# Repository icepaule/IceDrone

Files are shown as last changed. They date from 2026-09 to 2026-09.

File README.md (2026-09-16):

# IceDrone

A small, 3D-printable brushed quadcopter built around the **Seeed Studio XIAO ESP32-S3 Sense**, a **GY-91 IMU**, **VL6180X ToF sensor**, four **8520 brushed coreless motors** and 75/76 mm propellers. The project combines an Open32Drone-derived flight stack with Wi-Fi camera streaming and a modular printable airframe sized for an **Anycubic Kobra S1**.

> **Current mechanical design: Airframe V2.**  
> **Current electrical design: V3.4 HW-VERIFIED.** V3.2/V3.3 drawings are obsolete for soldering.  
> Full documentation: **[icepaule.github.io/IceDrone](https://icepaule.github.io/IceDrone/)** and [`docs/`](docs/).

## Electrical V3.4

The current 70×30 mm perfboard prototype and the custom-PCB path share the same V3.4 electrical profile:

- M1 rear-left: GPIO4 / D3
- M2 rear-right: **GPIO44 / D7**
- M3 front-right: GPIO6 / D5
- M4 front-left: GPIO5 / D4
- I2C: SDA GPIO2 / D1, SCL GPIO43 / D6; firmware uses `Wire.begin(2, 43)`
- motor flyback: SS34-class ≥3 A Schottky
- C1: 470 µF / 10 V low-ESR
- C2: 100 µF / 10 V low-ESR
- raw 1S LiHV is **not** fed directly into XIAO 5V/BAT; V3.4 uses an off-board 1S→5 V boost followed by D5
- photographed VL6180X order: `VIN | 2V8 | GND | GPIO | SHDN | SCL | SDA`

For the temporary perfboard build use **[`docs/10_PERFBOARD_V34_SOLDERING_DE.md`](docs/10_PERFBOARD_V34_SOLDERING_DE.md)** and the machine-readable files in `hardware/`.

## Airframe V2

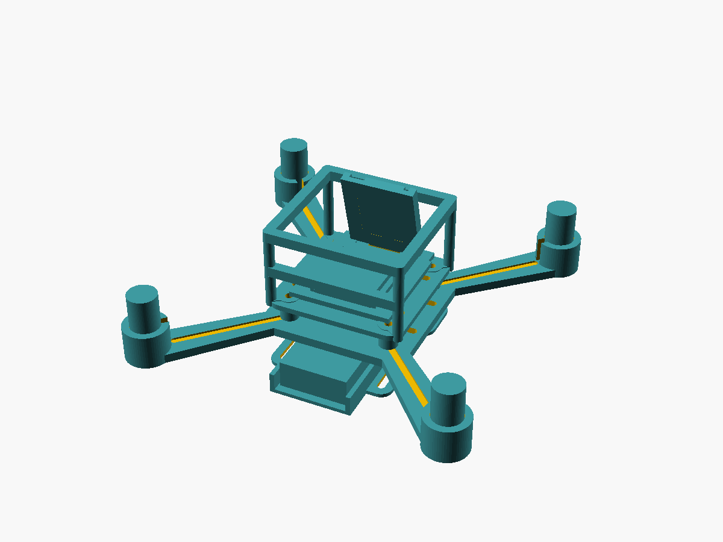
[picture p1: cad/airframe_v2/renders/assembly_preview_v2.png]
IceDrone Airframe V2 assembly


The current airframe is a modular **123 mm Quad-X** design with dedicated mounts for the 1S battery, electronics deck, XIAO ESP32-S3 Sense camera board, GY-91 IMU and a lightweight flight cage or closed canopy.

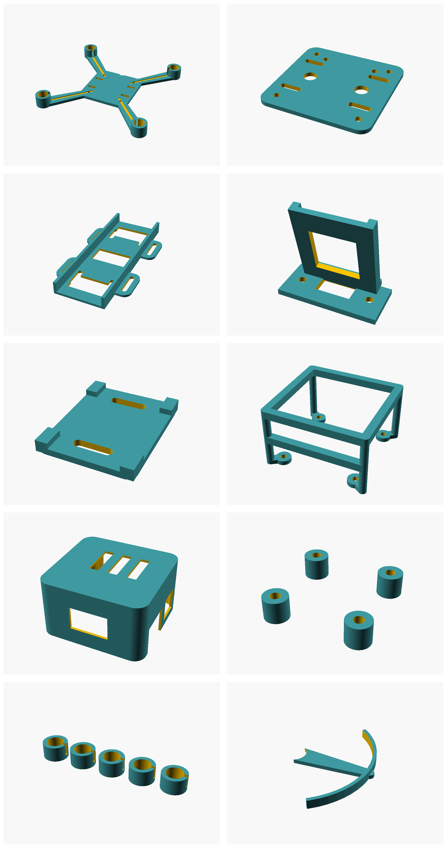
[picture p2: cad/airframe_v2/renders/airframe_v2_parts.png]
Airframe V2 printable parts


Detailed part descriptions, OpenSCAD sources, STL downloads, Kobra S1 print settings and validation notes are in **[`cad/airframe_v2/`](cad/airframe_v2/)**.

### Main printable parts

| Part | Preview | Source / STL |
|---|---|---|
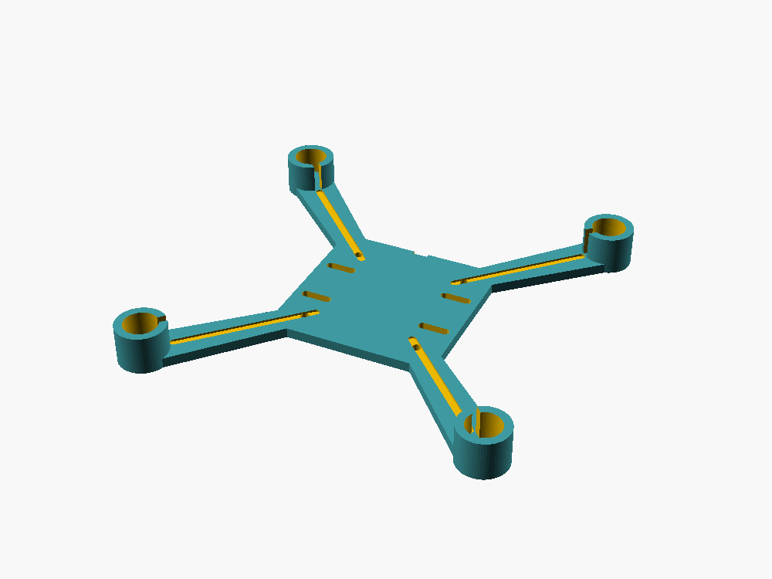
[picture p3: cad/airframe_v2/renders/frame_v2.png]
| Main Quad-X frame |  | [`frame_v2.scad`](cad/airframe_v2/scad/frame_v2.scad) · [`frame_v2.stl`](cad/airframe_v2/stl/frame_v2.stl) |
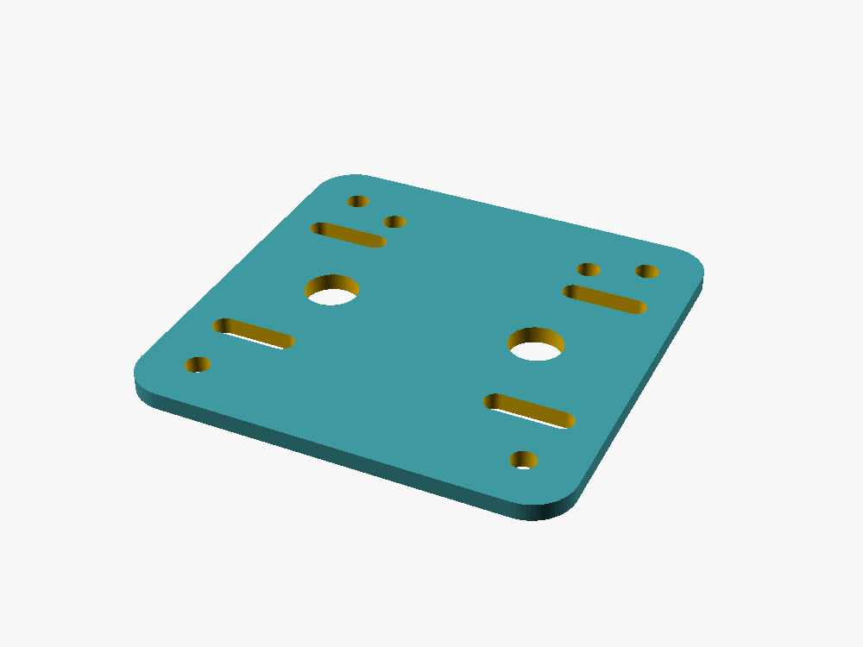
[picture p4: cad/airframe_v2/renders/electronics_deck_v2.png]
| Electronics deck |  | [`electronics_deck_v2.scad`](cad/airframe_v2/scad/electronics_deck_v2.scad) · [`electronics_deck_v2.stl`](cad/airframe_v2/stl/electronics_deck_v2.stl) |
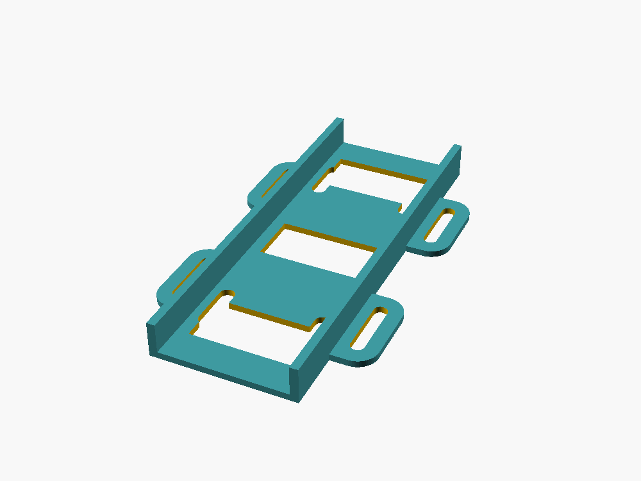
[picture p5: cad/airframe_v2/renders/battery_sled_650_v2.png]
| Battery sled |  | [`battery_sled_650_v2.scad`](cad/airframe_v2/scad/battery_sled_650_v2.scad) · [`battery_sled_650_v2.stl`](cad/airframe_v2/stl/battery_sled_650_v2.stl) |
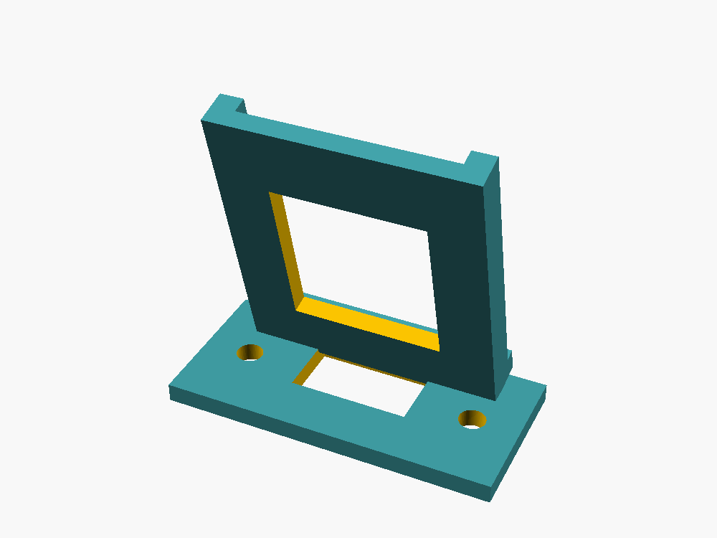
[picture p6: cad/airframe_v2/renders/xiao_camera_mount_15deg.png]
| XIAO camera mount |  | [`xiao_camera_mount_15deg.scad`](cad/airframe_v2/scad/xiao_camera_mount_15deg.scad) · [`xiao_camera_mount_15deg.stl`](cad/airframe_v2/stl/xiao_camera_mount_15deg.stl) |
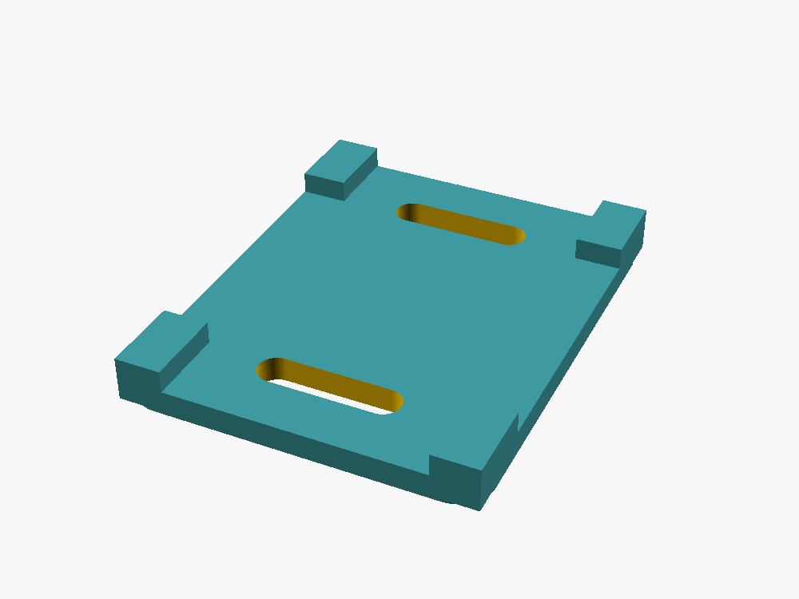
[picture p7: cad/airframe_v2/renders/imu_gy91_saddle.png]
| GY-91 IMU saddle |  | [`imu_gy91_saddle.scad`](cad/airframe_v2/scad/imu_gy91_saddle.scad) · [`imu_gy91_saddle.stl`](cad/airframe_v2/stl/imu_gy91_saddle.stl) |
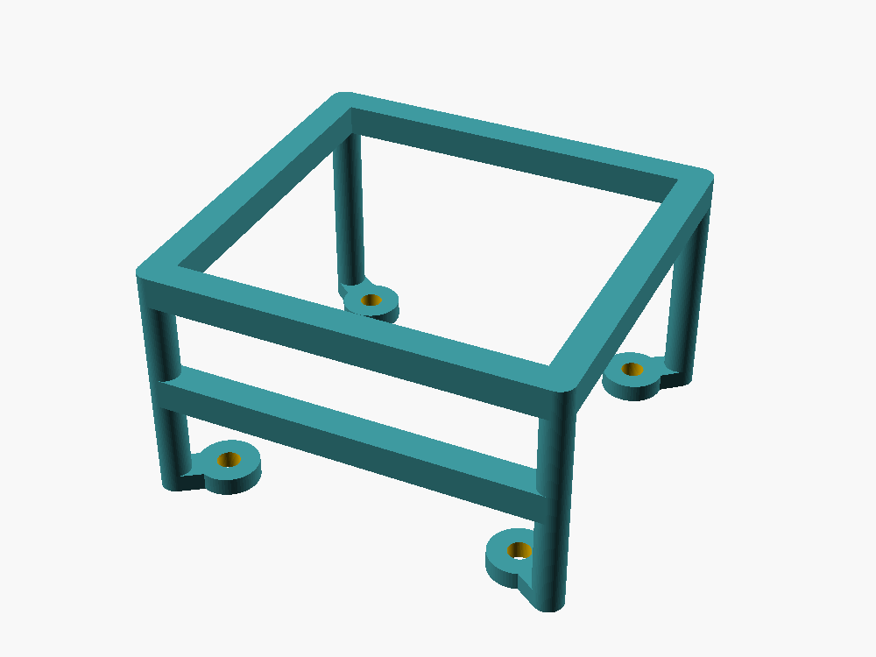
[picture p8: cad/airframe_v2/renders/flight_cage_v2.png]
| Flight cage |  | [`flight_cage_v2.scad`](cad/airframe_v2/scad/flight_cage_v2.scad) · [`flight_cage_v2.stl`](cad/airframe_v2/stl/flight_cage_v2.stl) |
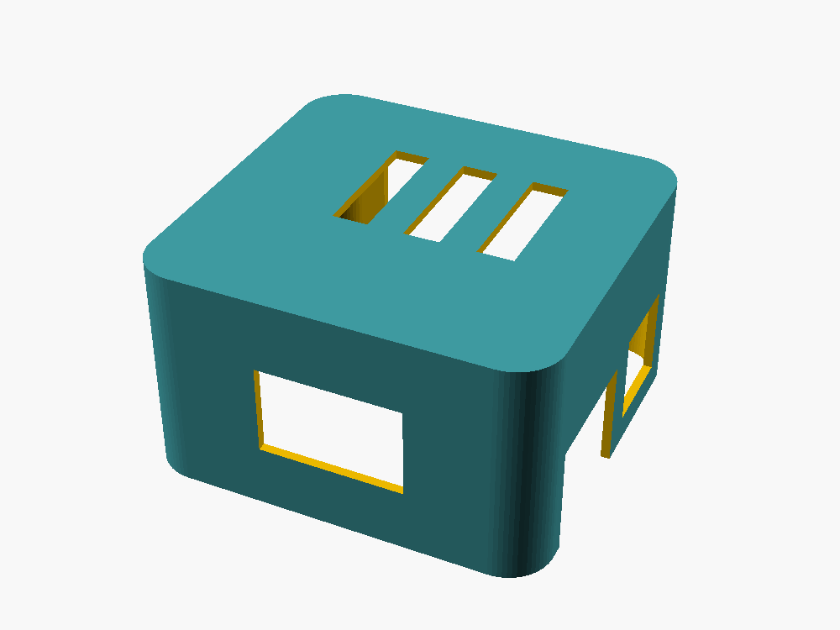
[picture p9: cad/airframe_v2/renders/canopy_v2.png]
| Closed canopy |  | [`canopy_v2.scad`](cad/airframe_v2/scad/canopy_v2.scad) · [`canopy_v2.stl`](cad/airframe_v2/stl/canopy_v2.stl) |
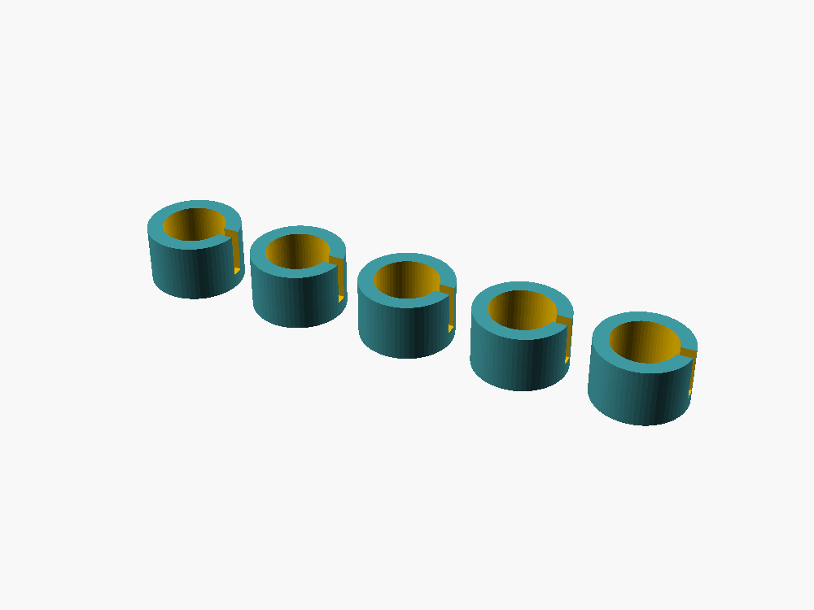
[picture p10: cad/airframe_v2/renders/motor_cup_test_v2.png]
| Motor-cup fit test |  | [`motor_cup_test_v2.scad`](cad/airframe_v2/scad/motor_cup_test_v2.scad) · [`motor_cup_test_v2.stl`](cad/airframe_v2/stl/motor_cup_test_v2.stl) |

## Propellers and replacement CAD

The purchased 75 mm propellers can be used directly. Parametric replacement/test models are kept separately under [`cad/propellers/`](cad/propellers/) so the flight airframe and experimental propeller work remain clearly separated.

| Standard 75 mm | Experimental toroidal / low-noise concept |
|---|---|
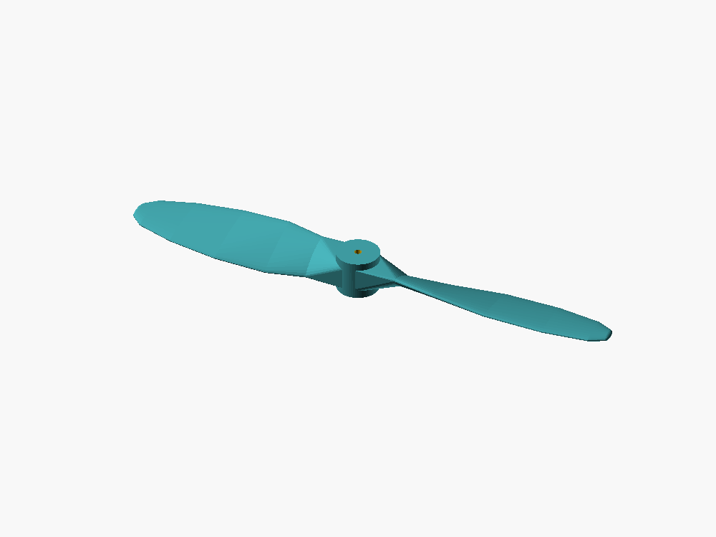
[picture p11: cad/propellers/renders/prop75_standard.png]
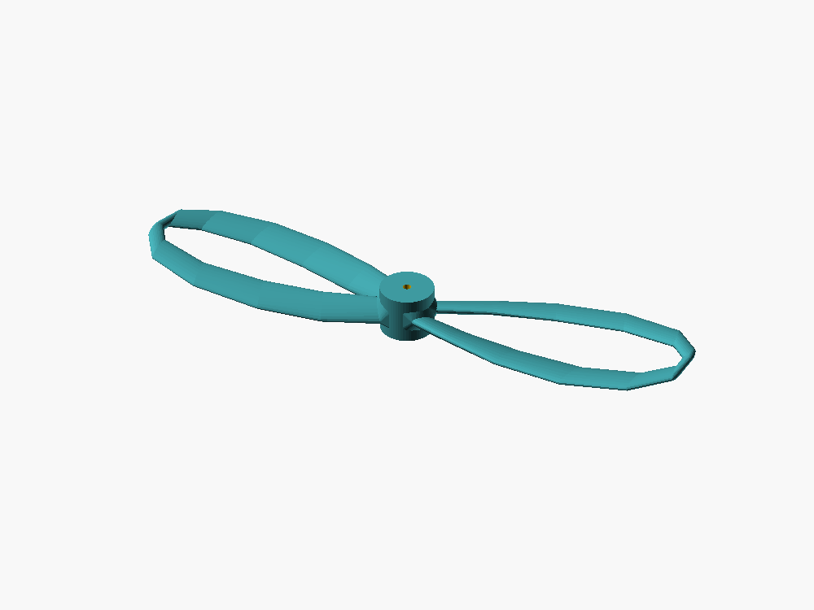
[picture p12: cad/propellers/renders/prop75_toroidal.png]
|  |  |

The repository includes CW/CCW STL exports and a 1 mm shaft-fit coupon. The toroidal model is experimental and should be bench-tested for current draw, vibration, balance and thrust before flight use.

## Design goals

- mostly printable micro quadcopter
- **123 mm diagonal motor-center wheelbase**
- **8520 brushed motors**, nominal 1.0 mm shafts
- **75/76 mm two-blade CW/CCW propellers**
- target takeoff mass around **60–80 g**
- XIAO ESP32-S3 Sense as flight/camera computer
- QVGA MJPEG live video over 2.4 GHz Wi-Fi
- MAVLink telemetry/control over UDP 14550
- stabilized/manual first-flight target
- printable on an Anycubic Kobra S1 with a 0.4 mm nozzle

## Repository layout

```text
.
├── README.md
├── bom/
├── cad/
│   ├── airframe_v2/
│   │   ├── scad/
│   │   ├── stl/
│   │   └── renders/
│   └── propellers/
│       ├── scad/
│       ├── stl/
│       └── renders/
├── docs/
├── firmware/
└── hardware/
```

## Quick start

1. Read [`docs/01_BOM.md`](docs/01_BOM.md) and [`docs/02_ELECTRICAL.md`](docs/02_ELECTRICAL.md); V3.4 is authoritative.
2. If building the temporary 70×30 mm perfboard, follow [`docs/10_PERFBOARD_V34_SOLDERING_DE.md`](docs/10_PERFBOARD_V34_SOLDERING_DE.md) hole by hole and multimeter-test each stage.
3. Print [`cad/airframe_v2/stl/motor_cup_test_v2.stl`](cad/airframe_v2/stl/motor_cup_test_v2.stl) before committing to the full frame.
4. Print the Airframe V2 parts using the settings in [`docs/03_MECHANICAL.md`](docs/03_MECHANICAL.md).
5. Assemble and power electronics **without propellers**, following [`docs/05_BUILD_AND_TEST.md`](docs/05_BUILD_AND_TEST.md).
6. Run the V3.4 bench firmware in [`firmware/bench_test/`](firmware/bench_test/) and verify IMU orientation and every motor channel.
7. Only after all bench checks pass, install balanced propellers and continue with [`docs/06_FIRST_FLIGHT.md`](docs/06_FIRST_FLIGHT.md).

## Primary references

- Open32Drone: https://github.com/npu-ius-lab/open32drone
- ESP-FLY: https://github.com/Seeed-Projects/Co-Create_ESP-FLY
- XIAO ESP32-S3 Sense: https://wiki.seeedstudio.com/xiao_esp32s3_getting_started/

## Important safety rule

**Never test motor channels, arming logic, mixer direction or firmware changes with propellers fitted.** Verify motor order and direction at low output first. Printed propellers in particular require careful balancing and restrained bench testing before flight.

## License and attribution

Project documentation, original CAD and bench-test code are provided under Apache-2.0 unless a file states otherwise. Open32Drone source is not duplicated here. See [`NOTICE`](NOTICE) and [`LICENSE`](LICENSE).

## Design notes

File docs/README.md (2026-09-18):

# IceDrone Documentation

IceDrone is a small, 3D-printable brushed quadcopter built around the **Seeed Studio XIAO ESP32-S3 Sense**, **GY-91 IMU**, VL6180X ToF sensor, 8520 motors and the current **Airframe V2** mechanical stack.

Airframe V2 assembly

This documentation belongs to [github.com/icepaule/IceDrone](https://github.com/icepaule/IceDrone) and is also published at **[icepaule.github.io/IceDrone](https://icepaule.github.io/IceDrone/)**.

## Table of contents

| # | Chapter | Covers |
|---:|---|---|
| 01 | [Bill of Materials](01_BOM.md) | Current V3.4 parts and electrical requirements |
| 02 | [Electrical](02_ELECTRICAL.md) | V3.4 power architecture, motor stages, pin map, sensors |
| 03 | [Mechanical](03_MECHANICAL.md) | Airframe V2, printable parts, STL/SCAD, Kobra S1 settings, CG |
| 04 | [Firmware](04_FIRMWARE.md) | Open32Drone strategy, build settings, video/MAVLink design rules |
| 05 | [Build and Test](05_BUILD_AND_TEST.md) | Step-by-step assembly and bring-up |
| 06 | [First Flight](06_FIRST_FLIGHT.md) | Test environment, hop/hover phases, acceptance criteria |
| 07 | [Safety and Legal (DE/EU)](07_SAFETY_AND_LEGAL_DE.md) | Workshop safety and UAS legal notes |
| 08 | [Troubleshooting](08_TROUBLESHOOTING.md) | Common faults and causes |
| 09 | [Amazon.de Order List (DE)](09_AMAZON_ORDER_LIST_DE.md) | Dated marketplace shopping aid |
| 10 | [Perfboard V3.4 soldering (DE)](10_PERFBOARD_V34_SOLDERING_DE.md) | Hole-by-hole solder map, SMD practice, multimeter gates |
| 11 | [PCB-Reflow Sn42Bi58 (DE)](11_REFLOW_SN42BI58_DE.md) | Stencil, paste printing, YIHUA YH-853AAA profile, inspection |
| — | [Reflow Quick Card](REFLOW_QUICK_CARD_DE.md) | Condensed workbench checklist |
| — | [Sources](SOURCES.md) | Upstream projects and references |

## Current project status

| Area | Status |
|---|---|
| Electrical revision | **V3.4 HW-VERIFIED is authoritative**; V3.2/V3.3 are obsolete for soldering |
| Perfboard prototype | 70×30 mm V3.4 layout and detailed solder guide available |
| Custom PCB | **70×30 mm PCB and stencil received**; manual first-article assembly/reflow procedure documented |
| Reflow process | Sn42Bi58 low-temperature workflow for YIHUA YH-853AAA documented; separate `bom/reflow_bom.csv` available |
| Bill of materials | Updated for SS34-class motor flyback, 10 V bulk capacitors and regulated XIAO 5 V supply |
| Mechanical | **Airframe V2 current**; parametric OpenSCAD + STL + previews in `cad/airframe_v2/` |
| Propeller CAD | Standard and experimental toroidal models in `cad/propellers/` |
| Bench-test firmware | Available in `firmware/bench_test/`; V3.4 motor map uses GPIO4/44/6/5 |
| Camera Wi-Fi diagnostic | `firmware/camera_wifi_test/` streams MJPEG over the existing Wi-Fi LAN |
| Flight-critical firmware | Tracks upstream Open32Drone; motor mapping/rotation, IMU calibration and battery calibration still require full hardware bring-up |

## V3.4 electrical highlights

- M1 GPIO4/D3
- M2 **GPIO44/D7**
- M3 GPIO6/D5
- M4 GPIO5/D4
- I2C SDA GPIO2/D1, SCL GPIO43/D6; firmware must call `Wire.begin(2, 43)`
- D1-D4 = SS34-class ≥3 A Schottky
- C1 = 470 µF / 10 V low-ESR
- C2 = 100 µF / 10 V low-ESR
- raw LiHV is not connected directly to XIAO 5V/BAT; use 1S→5 V boost + D5
- photographed VL6180X order: VIN, 2V8, GND, GPIO, SHDN, SCL, SDA

## Related files

- [`../hardware/perfboard_v34_netlist.csv`](../hardware/perfboard_v34_netlist.csv) — authoritative perfboard connections
- [`../hardware/perfboard_v34_pin_matrix.csv`](../hardware/perfboard_v34_pin_matrix.csv) — V3.4 external pin map
- [`assets/perfboard_v34_solder_side.svg`](assets/perfboard_v34_solder_side.svg) — physically mirrored rear-view solder map
- [`../hardware/pinmap.csv`](../hardware/pinmap.csv) — XIAO/GPIO mapping
- [`../hardware/motor_stage_netlist.csv`](../hardware/motor_stage_netlist.csv) — motor/power component netlist
- [`../bom/reflow_bom.csv`](../bom/reflow_bom.csv) — tools/consumables for stencil + Sn42Bi58 reflow
- [`assets/stencil_setup_v34.svg`](assets/stencil_setup_v34.svg) — oversized-stencil setup
- [`assets/reflow_profile_sn42bi58.svg`](assets/reflow_profile_sn42bi58.svg) — low-temperature profile reference
- [`assets/reflow_real_stencil_fixture_v34.jpg`](assets/reflow_real_stencil_fixture_v34.jpg) — real stencil/clamping setup
- [`assets/reflow_real_yihua_setup_v34.jpg`](assets/reflow_real_yihua_setup_v34.jpg) — real YIHUA setup / mechanical fit reference
- [`../firmware/bench_test/`](../firmware/bench_test/) — pre-flight bench firmware
- [`../cad/airframe_v2/`](../cad/airframe_v2/) — current airframe CAD
- [`../LICENSE`](../LICENSE), [`../NOTICE`](../NOTICE) — licensing

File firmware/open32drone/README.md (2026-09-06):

# Open32Drone integration

`vendor/open32drone` is a git submodule pointing at the upstream
[Open32Drone](https://github.com/npu-ius-lab/open32drone) repository. Do not edit
files inside the submodule directly — apply `v1.patch` on top of a clean
checkout instead, so upstream updates (`git submodule update --remote`) stay a
clean rebase target.

## What `v1.patch` changes

Applies the two "Local V1 choices" from `docs/04_FIRMWARE.md` that differ from
upstream's own defaults:

- `CAMERA_JPEG_QUALITY`: 10 → 18
- `OPTICAL_FLOW_ENABLED`: 1 → 0 (disabled for V1)

Everything else in that policy list (MAVLink port 14550, camera enabled,
QVGA, one viewer maximum, SBUS disabled, battery divider 2.0) already matches
upstream's defaults and needs no patch.

## Build and flash

```bash
# from the repo root, once:
git submodule update --init vendor/open32drone

cd vendor/open32drone
git apply ../../firmware/open32drone/v1.patch
cd software

arduino-cli core install esp32:esp32@3.3.6 \
  --additional-urls https://espressif.github.io/arduino-esp32/package_esp32_index.json
arduino-cli lib install "FlixPeriph@1.10.4" "MAVLink@2.0.25"

arduino-cli compile --clean \
  --fqbn 'esp32:esp32:XIAO_ESP32S3:PSRAM=opi,PartitionScheme=default_8MB,FlashMode=dio' \
  --output-dir /tmp/open32drone-build firmware

arduino-cli upload -p /dev/ttyACM0 \
  --fqbn 'esp32:esp32:XIAO_ESP32S3:PSRAM=opi,PartitionScheme=default_8MB,FlashMode=dio' \
  --input-dir /tmp/open32drone-build

# afterwards, restore the clean submodule checkout:
cd ../../..
git -C vendor/open32drone checkout -- .
```

## Verified 2026-09-06 (USB-only smoke test, submodule at `a49c037a`)

No IMU, motors, or battery wired — camera and Wi-Fi hardware only, propellers
off. Boot log confirmed:

- `Camera profile: QVGA quality 18, 10 FPS` — patch applied correctly.
- `softAP started: yes (IP 192.168.4.1)`, `Camera stream: http://192.168.4.1/stream`.
- `MAVLink UDP: bind OK local 14550 initial peer 192.168.4.255:14550`.
- `IMU: Error: 1` / `IMU initialization failed` — expected, no IMU wired yet
  (GY-91 arrives ~2026-09-16/21).
- No optical-flow setup attempted (`OPTICAL_FLOW_ENABLED=0` took effect).
- `Initializing complete`, then the CLI banner — firmware runs its full
  300 Hz loop without an IMU or optical flow present; nothing hangs or
  crash-loops on the missing sensors.

This only proves the firmware boots and its Wi-Fi/camera/MAVLink transport
work on this board. It is not a flight readiness check — Stages E through J
in `docs/05_BUILD_AND_TEST.md` (IMU orientation, motor mapping/rotation,
battery calibration, pre-prop checklist) still apply once the IMU and motor
hardware are installed.

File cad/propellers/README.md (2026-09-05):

# IceDrone 75 mm Propeller CAD

Parametric replacement and experimental propeller models for the 8520 brushed motor configuration used by IceDrone. The purchased molded 75 mm propellers remain the preferred baseline for first flight.

## Standard replacement model

Standard 75 mm propeller

- nominal diameter: 75 mm
- two blades
- 1.0 mm nominal motor shaft
- CW and CCW STL exports
- OpenSCAD source: [`scad/icedrone_prop_75mm_standard.scad`](scad/icedrone_prop_75mm_standard.scad)

STL:
- [`stl/IceDrone_75mm_Standard_CW.stl`](stl/IceDrone_75mm_Standard_CW.stl)
- [`stl/IceDrone_75mm_Standard_CCW.stl`](stl/IceDrone_75mm_Standard_CCW.stl)

## Experimental toroidal / low-noise model

Toroidal propeller

The toroidal model applies the looped-blade concept discussed in MIT Lincoln Laboratory's toroidal propeller work and in the referenced Slashcam article. It is an **experimental scaling to a 75 mm / 8520 brushed platform**; acoustic and efficiency results from larger prototypes should not be assumed to transfer directly.

OpenSCAD:
- [`scad/icedrone_prop_75mm_toroidal.scad`](scad/icedrone_prop_75mm_toroidal.scad)

STL:
- [`stl/IceDrone_75mm_Toroidal_Quiet_CW.stl`](stl/IceDrone_75mm_Toroidal_Quiet_CW.stl)
- [`stl/IceDrone_75mm_Toroidal_Quiet_CCW.stl`](stl/IceDrone_75mm_Toroidal_Quiet_CCW.stl)

References:
- https://www.ll.mit.edu/partner-us/available-technologies/toroidal-propeller-0
- https://www.slashcam.de/news/single/Weniger-Sirren--Neues-Rotorendesign-macht-Drohnen--17711.html

## 1 mm shaft-fit coupon

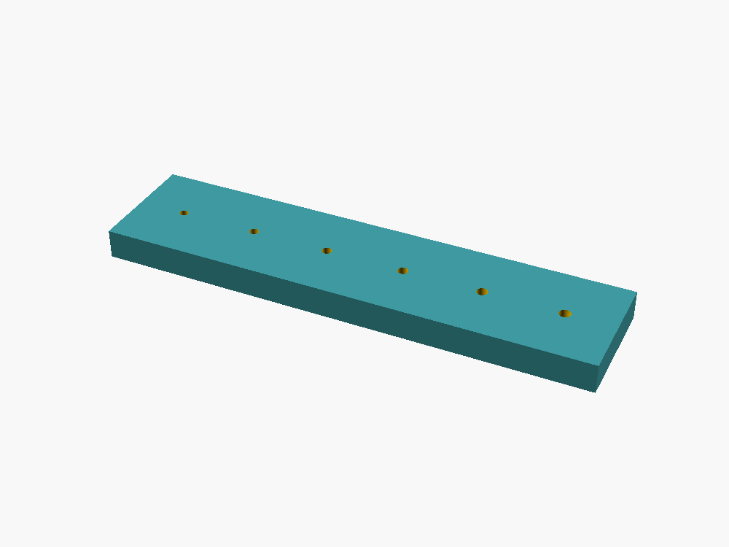
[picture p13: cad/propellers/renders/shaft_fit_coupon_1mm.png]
Shaft-fit coupon


Print the fit coupon before relying on a printed press-fit hub. It contains several hole sizes around the nominal 1.0 mm shaft so printer/material shrinkage can be measured.

- OpenSCAD: [`scad/shaft_fit_coupon_1mm.scad`](scad/shaft_fit_coupon_1mm.scad)
- STL: [`stl/IceDrone_1mm_Shaft_Fit_Coupon.stl`](stl/IceDrone_1mm_Shaft_Fit_Coupon.stl)

## Printing and test safety

Printed propellers are high-RPM rotating parts. Inspect them for layer defects, balance them, run initial tests restrained and at low PWM, and increase speed only while monitoring vibration and motor current. Do not stand in the propeller plane during testing.

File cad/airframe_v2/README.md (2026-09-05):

# IceDrone Airframe V2

This directory contains the **current** printable mechanical design for IceDrone. Airframe V2 replaces the earlier V1 frame/cradle set on `main` and provides a complete modular stack for the battery, electronics, XIAO ESP32-S3 Sense camera board, GY-91 IMU and protection cage/canopy.

Airframe V2 assembly preview

## Design basis

- 123 mm Quad-X diagonal motor-center wheelbase
- motor centers at ±43.49 mm X/Y
- 8520 brushed coreless motors, nominal 8.5 mm diameter / 1.0 mm shaft
- 75/76 mm propellers
- shared 30 × 30 mm M2 mechanical stack
- 1S 550–650 mAh battery, nominal envelope up to about 62 × 20 × 8 mm
- XIAO ESP32-S3 Sense forward camera mount
- GY-91 IMU close to the geometric center
- Anycubic Kobra S1 / 0.4 mm nozzle target

> **Measure before the final flight print.** Marketplace GY-91 boards, 8520 motor cans and 1S batteries vary. Relevant dimensions are parameters in `scad/icedrone_v2_lib.scad`.

Airframe V2 printable parts

## Part preview and purpose

| Preview | OpenSCAD | STL | Purpose |
|---|---|---|---|
| Frame | [`frame_v2.scad`](scad/frame_v2.scad) | [`frame_v2.stl`](stl/frame_v2.stl) | Main 123 mm Quad-X frame with four 8520 motor cups and central 30 × 30 mm stack. |
| Electronics deck | [`electronics_deck_v2.scad`](scad/electronics_deck_v2.scad) | [`electronics_deck_v2.stl`](stl/electronics_deck_v2.stl) | Carrier for the MOSFET/motor stage or small perfboard/PCB. |
| XIAO mount | [`xiao_camera_mount_15deg.scad`](scad/xiao_camera_mount_15deg.scad) | [`xiao_camera_mount_15deg.stl`](stl/xiao_camera_mount_15deg.stl) | Forward camera holder, about 15° nose-down, open for cooling. |
| GY-91 saddle | [`imu_gy91_saddle.scad`](scad/imu_gy91_saddle.scad) | [`imu_gy91_saddle.stl`](stl/imu_gy91_saddle.stl) | Centered IMU saddle; TPU 95A preferred for mild vibration isolation. |
| Battery sled | [`battery_sled_650_v2.scad`](scad/battery_sled_650_v2.scad) | [`battery_sled_650_v2.stl`](stl/battery_sled_650_v2.stl) | Lower sliding battery cradle for CG adjustment. |
| Flight cage | [`flight_cage_v2.scad`](scad/flight_cage_v2.scad) | [`flight_cage_v2.stl`](stl/flight_cage_v2.stl) | Lightweight recommended protection over the electronics stack. |
| Canopy | [`canopy_v2.scad`](scad/canopy_v2.scad) | [`canopy_v2.stl`](stl/canopy_v2.stl) | Closed, heavier protection option. |
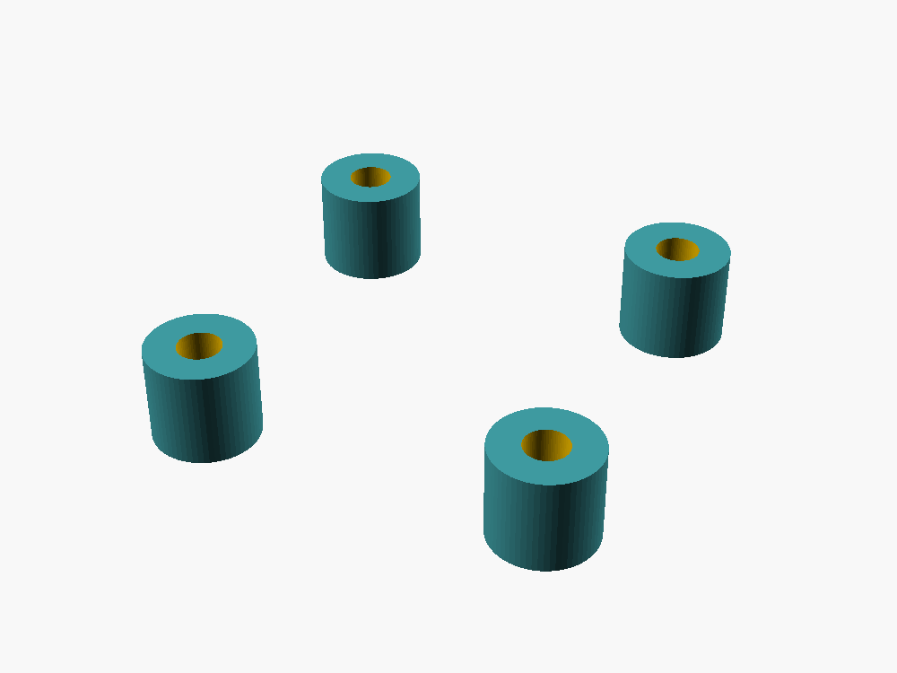
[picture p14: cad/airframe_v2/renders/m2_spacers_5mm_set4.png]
M2 spacers
|  | [`m2_spacers_5mm_set4.scad`](scad/m2_spacers_5mm_set4.scad) | [`m2_spacers_5mm_set4.stl`](stl/m2_spacers_5mm_set4.stl) | Four 5 mm M2 spacers. |
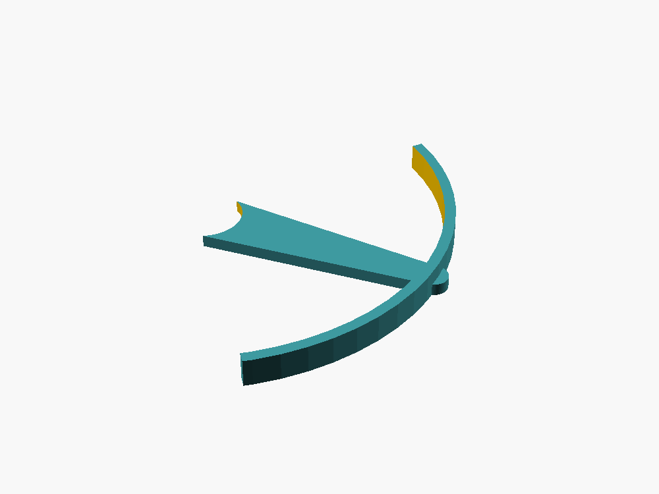
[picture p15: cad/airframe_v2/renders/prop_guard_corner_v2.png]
Prop guard
|  | [`prop_guard_corner_v2.scad`](scad/prop_guard_corner_v2.scad) | [`prop_guard_corner_v2.stl`](stl/prop_guard_corner_v2.stl) | Optional single-corner guard; print four if used. |
| Motor cup test | [`motor_cup_test_v2.scad`](scad/motor_cup_test_v2.scad) | [`motor_cup_test_v2.stl`](stl/motor_cup_test_v2.stl) | Five 8520 press-fit samples: 8.55–8.75 mm. Print this first. |

[`icedrone_v2_lib.scad`](scad/icedrone_v2_lib.scad) contains the shared parametric geometry. [`assembly_preview_v2.scad`](scad/assembly_preview_v2.scad) is a non-printable scene used for the assembly visualization.

## Recommended flight stack

1. `battery_sled_650_v2.stl`
2. `frame_v2.stl`
3. four 5 mm M2 spacers
4. `electronics_deck_v2.stl`
5. `flight_cage_v2.stl` or `canopy_v2.stl`

## Motor cup calibration

Print `stl/motor_cup_test_v2.stl` first and test the actual delivered motors. Use the smallest cup with a firm press fit that does not deform the motor or crack the cup, then set `motor_id` in `scad/icedrone_v2_lib.scad` and re-render the frame if required.

## Kobra S1 guidance

| Part | Material | Layer | Walls | Infill | Support |
|---|---|---:|---:|---:|---|
| Frame | PETG | 0.16–0.20 mm | 4 | 100% | none |
| Electronics deck | PETG | 0.16–0.20 mm | 3–4 | 60–100% | none |
| XIAO mount | PETG/TPU 95A | 0.16–0.20 mm | 3 | 50–100% / 25–40% | normally none |
| IMU saddle | TPU 95A preferred | 0.20 mm | 3 | 20–35% | none |
| Battery sled | PETG/TPU | 0.16–0.20 mm | 3 | 50–100% | none |
| Flight cage | PETG | 0.16 mm | 3 | 100% | support top bridges only |
| Canopy | PETG | 0.16–0.20 mm | 3 | 60–100% | roof-down; support as needed |

## Validation

- [`PARTS_MANIFEST.csv`](PARTS_MANIFEST.csv)
- [`STL_VALIDATION.csv`](STL_VALIDATION.csv)

The exported flight STL files were checked as closed meshes. Multi-part test/set STL files intentionally contain more than one disconnected body.

## Safety

Complete all electrical, motor-order, motor-direction, IMU-orientation and failsafe tests **without propellers installed**. Use eye protection and restrain the airframe for the first powered propeller tests.

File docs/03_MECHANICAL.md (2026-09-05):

[← Docs index](README.md)

# 03 - Mechanical

The **Airframe V2** in [`cad/airframe_v2/`](../cad/airframe_v2/) is the current mechanical design. The previous V1 frame and cradle files have been removed from `main`; they remain recoverable through Git history.

Airframe V2 assembly

## Frame geometry

- 123 mm diagonal Quad-X motor-center wheelbase
- motor centers at ±43.49 mm X/Y
- adjacent motor spacing about 87 mm
- 8520 brushed motors, nominal 8.5 mm body diameter
- 75/76 mm propellers
- shared 30 × 30 mm M2 stack
- battery mounted underneath for longitudinal CG adjustment

## Printable stack

1. `battery_sled_650_v2.stl`
2. `frame_v2.stl`
3. four 5 mm M2 spacers
4. `electronics_deck_v2.stl`
5. `flight_cage_v2.stl` **or** `canopy_v2.stl`

The XIAO camera mount faces forward. Keep the GY-91 close to the geometric center and aligned with the frame axes.

Airframe V2 printable parts

## Part files

All current OpenSCAD sources and STL exports are in [`cad/airframe_v2/`](../cad/airframe_v2/). Each printable part has a preview image in `cad/airframe_v2/renders/` and is documented in the Airframe V2 README.

The shared parametric geometry is in `cad/airframe_v2/scad/icedrone_v2_lib.scad`; the small wrapper SCAD files render one selected part each.

## 8520 motor-cup calibration

Print `motor_cup_test_v2.stl` before the full frame. It contains 8.55 / 8.60 / 8.65 / 8.70 / 8.75 mm cup IDs. Use the smallest size that accepts the actual motor with a firm press fit without deforming the motor can or cracking the cup. Then adjust `motor_id` in `icedrone_v2_lib.scad` if required.

## Battery and center of gravity

The default sled targets a 1S pack around 550–650 mAh and an envelope up to roughly 62 × 20 × 8 mm. Measure the delivered battery before the final print and slide it longitudinally until the assembled aircraft balances at the geometric center.

## Kobra S1 print settings

| Part | Material | Layer | Walls | Infill | Support |
|---|---|---:|---:|---:|---|
| Main frame | PETG | 0.16–0.20 mm | 4 | 100% | none |
| Electronics deck | PETG | 0.16–0.20 mm | 3–4 | 60–100% | none |
| Battery sled | PETG/TPU | 0.16–0.20 mm | 3 | 50–100% | none |
| XIAO mount | PETG/TPU 95A | 0.16–0.20 mm | 3 | 50–100% / 25–40% | normally none |
| IMU saddle | TPU 95A preferred | 0.20 mm | 3 | 20–35% | none |
| Flight cage | PETG | 0.16 mm | 3 | 100% | tree/build-plate support for top bridges only |
| Canopy | PETG | 0.16–0.20 mm | 3 | 60–100% | print roof-down; support as required |

## Propeller CAD

Replacement/test propeller models are in [`cad/propellers/`](../cad/propellers/): standard 75 mm two-blade CW/CCW, experimental toroidal/low-noise CW/CCW, and a 1 mm shaft-fit coupon. The purchased molded propellers remain the preferred starting point.

## Safety

Perform electrical, motor-order, motor-direction, IMU-orientation and failsafe tests **without propellers installed**. Fit propellers only after all prop-off checks pass. Use eye protection and restrain the aircraft for initial powered propeller tests.

---
[← 02 - Electrical](02_ELECTRICAL.md) | [Docs index](README.md) | Next: [04 - Firmware →](04_FIRMWARE.md)

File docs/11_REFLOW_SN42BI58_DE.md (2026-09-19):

[← Docs index](README.md)

# 11 - PCB-Reflow mit Sn42Bi58 und YIHUA YH-853AAA

**Projekt:** IceDrone V3.4, 70 × 30 mm PCB  
**Paste:** Sn42Bi58, bleifrei, eutektisch, Schmelzpunkt 138 °C  
**Werkzeug:** YIHUA YH-853AAA mit 120 × 120 mm Vorheizer + Heißluft  
**Stand:** 2026-09-18

> Diese Anleitung ist für die erste manuelle Bestückung des IceDrone-V3.4-PCBs mit Stencil gedacht. Sie ist bewusst konservativ ausgelegt. Die Temperaturanzeige der Station ist **nicht** identisch mit der Temperatur am Lötpad. Ein Thermoelement am PCB ist die beste Kontrolle. Wenn die Herstellerangaben der tatsächlich gelieferten Paste von dieser Anleitung abweichen, haben die Angaben auf Paste/Datenblatt Vorrang.

Gesamtablauf

## 0. Realer IceDrone-Aufbau

Die folgenden Fotos dokumentieren den **tatsächlich vorhandenen Stencil-Halter und die YIHUA YH-853AAA**. Sie sind damit die praktische Referenz für diese Anleitung.

### Stencil auf der Spannvorrichtung

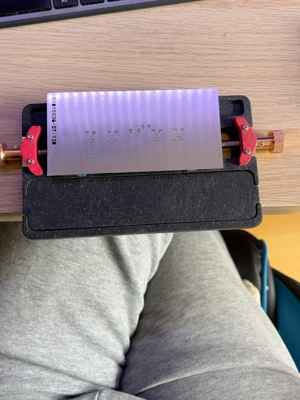
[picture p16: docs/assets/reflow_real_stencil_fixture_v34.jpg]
Realer Stencil-Aufbau


Der große Edelstahl-Stencil liegt auf der Spannvorrichtung über dem kleinen IceDrone-PCB. Das ist grundsätzlich passend: Der Stencil darf deutlich größer als die Platine sein, solange er über dem PCB plan aufliegt und sich beim Rakeln nicht durchbiegt. Die roten Klemmbacken dürfen den Stencil bzw. das PCB beim Ausrichten nicht verschieben.

### Spannvorrichtung an der YIHUA

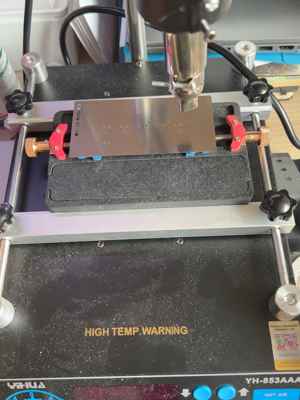
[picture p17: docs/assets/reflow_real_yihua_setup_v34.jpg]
Realer Aufbau an der YIHUA


> **Sehr wichtig:** Auf diesem Foto ist der Stencil noch unter der Heißluftdüse zu sehen. Das Foto dokumentiert nur die mechanische Passprobe/Ausrichtung. **Für den tatsächlichen Reflow muss der Stencil vollständig entfernt sein, bevor Vorheizer oder Heißluft eingeschaltet werden.** Auf die YIHUA kommt zum Reflow ausschließlich das bereits mit Paste bedruckte und mit SMD-Bauteilen bestückte PCB.

Die Spannvorrichtung kann zum kalten Ausrichten genutzt werden. Für das Aufheizen soll das PCB anschließend möglichst frei, eben und mittig über der Vorheizzone liegen, damit Metall-Stencil und massive Halter keine unnötigen Wärmebrücken bilden.

## 1. Warum Sn42Bi58 hier anders behandelt wird

Sn42Bi58 ist ein eutektisches Niedrigtemperaturlot. Solidus und Liquidus liegen bei ungefähr **138 °C**. Dadurch kann die Platine deutlich kühler verarbeitet werden als mit SAC305. Als Referenz zeigt ein industrielles Low-Temperature-Profil für eine sehr ähnliche Sn/Bi-Legierung einen langsamen Ramp von Raumtemperatur über 90 °C und 130 °C, dann einen Peak um **165 °C** und anschließendes Abkühlen.

Für die YIHUA bedeutet das: Nicht versuchen, eine SAC305-Reflowtemperatur von 230–250 °C am PCB zu erreichen. Ziel ist vielmehr eine **Pad-/Bauteiltemperatur von ungefähr 155–165 °C** während des eigentlichen Reflows. Die Heißluft muss aufgrund der Wärmeverluste etwas höher eingestellt werden.

**Wichtig für IceDrone:** Bismut-Lote sind mechanisch spröder als typische SAC-Lote. Für diesen Prototyp ist Sn42Bi58 wegen des einfachen, schonenden Reflows praktisch. Motor- und Akkuanschlüsse müssen aber mechanisch entlastet werden; Steckverbinder und schwere Bauteile dürfen nicht über ihre Lötstellen als Zugentlastung dienen.

**Nicht mit dem vorhandenen bleihaltigen Sn60PbCu2 an derselben Lötstelle mischen.** Pb/Bi-Mischungen können niedrigschmelzende Phasen bilden und die Zuverlässigkeit verschlechtern. Für Korrekturen an Sn42Bi58-SMD-Lötstellen daher möglichst wieder Sn42Bi58 bzw. kompatibles bleifreies Material verwenden.

## 1.1 Tatsächlich gelieferte Paste geprüft

Die am 2026-09-19 fotografierte und gelieferte BEEYUIHF-Paste ist auf dem Etikett als **Sn42/Bi58**, **138 °C**, **Particles 25–45 µm** gekennzeichnet. Damit passt die reale Paste zum in dieser Anleitung verwendeten Niedrigtemperatur-Prozess.

Für diese Spritze bleibt das Zielprofil deshalb unverändert: PCB zunächst vorwärmen/soaken und anschließend nur so weit über 138 °C bringen, bis alle Lötstellen sichtbar sauber benetzen. Ein Peak am PCB von ungefähr 155–165 °C bleibt ein geeigneter Startbereich.

## 1.2 Eingegangene SMD-Bauteile: SS34 jetzt bestätigt

Das neue Mikroskopfoto zeigt auf dem größeren 2-poligen SMA/DO-214AC-Bauteil die Markierung **SS34**. Damit sind die vorgesehenen **D1–D4 Motor-Flyback-Schottkydioden** physisch vorhanden und nicht mehr nur über die Gehäuseform vermutet.

Für D1–D4 gilt beim Bestücken:
- Bauteil: SS34, 3-A/40-V-Schottky-Klasse;
- Gehäuse: SMA / DO-214AC;
- **Kathodenband zur VBAT-Seite** des jeweiligen Motorzweigs;
- bei optisch unklarer Bandmarkierung vor dem Setzen mit der Diodentest-Funktion des Multimeters verifizieren.

D5 bleibt ein separates Bauteil der >=1-A-Schottky-Klasse und ist nicht mit D1–D4 zu verwechseln.

## 1.3 Q1–Q4 MOSFETs identifiziert

Die für Q1–Q4 beschafften Transistoren stammen aus einer Amazon.de-Bestellung mit der Produktbeschreibung **„50 Pcs/Set N-Channel Field Effect Transistor A09T MOS Tube for AO3400 AO3400A SOT23.30V 5.8A“**. Damit ist das auf dem Foto sichtbare SOT-23-Bauteil der vorgesehenen **AO3400/AO3400A-Klasse** zuzuordnen.

Die Markierung **A09T** wird von mehreren 3400/AO3400-kompatiblen SOT-23-MOSFETs verwendet. Das für das IceDrone-Layout relevante Pinout ist **Pin 1 = Gate, Pin 2 = Source, Pin 3 = Drain**. Die genaue Orientierung auf dem PCB richtet sich nach dem V3.4-Footprint/Silkscreen und wird vor dem Setzen von Q1–Q4 noch einmal gegen die Bestückungsseite geprüft.

> Die vollständige Amazon-Bestellnummer wird absichtlich nicht im öffentlichen Repository dokumentiert; Produktbezeichnung und Bezugsquelle reichen für die technische Rückverfolgbarkeit aus.

## 1.4 Kondensator-Kit identifiziert

Für die Bulk-Kondensatoren steht das **925 pcs / 36 values Aluminum Capacitor Box Kit** zur Verfügung. Auf dem fotografierten Kasten sind unter anderem **470 µF / 10 V** und mehrere **100-µF-Werte ab 16 V** aufgeführt.

Diese Werte passen von Kapazität/Spannungsfestigkeit grundsätzlich zu C1/C2, **das Foto bzw. Kit-Label weist jedoch keine Low-ESR-Spezifikation nach**. Deshalb sind die Kit-Elkos kein freigegebener 1:1-Ersatz für die endgültige V3.4-Flugbestückung.

Wichtig: Die Kit-Kondensatoren sind radial bedrahtete Aluminium-Elkos. Vor einer eventuellen Bench-Nutzung muss zusätzlich geprüft werden, ob das gefertigte PCB dafür passende Bohrungen/Pads hat. Sind C1/C2 als SMD-Aluminium-Elko-Footprints ausgeführt, passen die radialen Teile mechanisch nicht direkt.

**C3 und die vier 100-nF-Motorkondensatoren kommen nicht aus diesem Elektrolyt-Kit.** Dafür werden separate Keramikkondensatoren benötigt.

## 1.5 SS14-Streifen bestätigt – aber nicht für D1–D4

Die drei vorhandenen Bauteilstreifen sind als **SS14, 1 A / 40 V im SMA-/DO-214AC-Gehäuse** bestätigt. Für die V3.4-Platine gilt trotzdem:

- **D1–D4:** benötigen **B340A-13-F / SS34-Klasse, 3 A / 40 V, SMA (DO-214AC)**. Die vorhandenen SS14 passen zwar mechanisch in die SMA-Footprints, sind dort aber elektrisch unterdimensioniert.
- **D5:** der Produktions-BOM sieht **1N5819W im SOD-123FL-Footprint** vor. Die vorhandenen SS14 sind elektrisch für diese Funktion ausreichend, passen aber voraussichtlich **nicht mechanisch** auf das kleinere D5-Footprint.

Darum werden die vorhandenen SS14 nicht in den ersten PCB-Reflow eingeplant. Der aktuelle Bestandsstatus steht in [`bom/pcb_smd_inventory_v34.csv`](../bom/pcb_smd_inventory_v34.csv).

## 1.6 Eurocircuits-Fertigungsunterlagen ausgewertet

Die gelieferten Eurocircuits-Unterlagen für die tatsächlich gefertigte V3.4-B70-Platine bestätigen die reale Leiterplatte als **70 × 30 mm, 2 Lagen, ca. 1.55 mm FR-4, bleifreie Oberfläche und elektrischen Test**. Die Bestellung war eine **Bare-PCB-Bestellung ohne Assembly/Components**.

Aus dem Produktions-Topview lässt sich für den Reflow zusätzlich direkt ableiten:

- **Q1–Q4:** SOT-23-Footprints wie vorgesehen.
- **D1–D4:** große SMA/DO-214AC-Footprints an den vier Motorstufen.
- **D5:** deutlich kleineres 2-Pad-Footprint im 5V/XIA-Bereich; vorhandene SS14 im SMA-Gehäuse sind mechanisch zu groß.
- **R1–R10 / C3:** kleine Chip-Footprints der 0603-Klasse.
- **C1/C2:** SMD-Aluminium-Elko-Footprints; keine radialen THT-Bohrungen. Das vorhandene BEEYUIHF-Radial-Elko-Sortiment ist daher nicht direkt für C1/C2 verwendbar.
- Die zwei Bulk-Elko-Landpatterns unterscheiden sich sichtbar in der Breite/Padteilung und entsprechen der bisherigen Planung mit ungefähr **8-mm-Klasse für C1** und **6.3-mm-Klasse für C2**.

Damit ist die offene Footprint-Frage für die Einkaufsliste praktisch geklärt: ein 0603-Sortiment kann die kleinen Passiven abdecken, die beiden Bulk-SMD-Elkos müssen jedoch footprintgerecht beschafft werden.

## 2. Reflow-BOM / Arbeitsplatz

Die maschinenlesbare Liste liegt unter [`bom/reflow_bom.csv`](../bom/reflow_bom.csv).

Unbedingt benötigt werden PCB, passender Stencil, Sn42Bi58-Lötpaste, Kapton-Tape, ein Rakel, Pinzette, Vergrößerung und die YIHUA-Station. Sehr empfohlen sind 99% IPA, fusselfreie Tücher, ESD-Unterlage und ein K-Thermoelement. Für Nacharbeit: No-Clean-Flux und feine Entlötlitze.

> **Solder Balls sind kein Ersatz für Stencil-Lötpaste.** Sie werden für BGA-Reballing verwendet und ergeben auf normalen SMD-Pads keine kontrollierte Lotmenge.

## 3. Vor dem ersten Pastendruck

### 3.1 Paste vorbereiten

Wenn die Paste kühl gelagert wurde, zunächst geschlossen auf Raumtemperatur kommen lassen. Nicht mit Heißluft oder auf dem Vorheizer erwärmen. Anschließend die Spritze vorsichtig durchkneten bzw. gemäß Herstellerangabe homogenisieren.

Die separat bestellte Flux-Paste wird **nicht unter die Stencil-Paste geschmiert**. Die Lötpaste enthält bereits Flussmittel. Zusätzlicher Flux ist nur für spätere Hand-Nacharbeit gedacht.

### 3.2 PCB reinigen

1. PCB an den Kanten anfassen.
2. Pads mit 99% Isopropanol und fusselfreiem Tuch reinigen.
3. Vollständig trocknen lassen.
4. Danach Pads nicht mehr mit den Fingern berühren.

### 3.3 Stencil größer als PCB: kein Problem

Der Stencil wird **nur zum Drucken der Paste** verwendet. Er wird vor dem Bestücken wieder abgenommen und kommt niemals auf den Vorheizer.

Stencil-Aufbau

**Reale Umsetzung mit deiner Spannvorrichtung:**

Stencil auf deiner Vorrichtung

Die Vorrichtung ersetzt die einfache Klebeband-/Shim-Lösung teilweise sehr gut. Entscheidend bleibt, dass das PCB selbst nicht wackelt, die Oberkante des PCB und etwaige Auflagen eine plane Fläche ergeben und die Stencil-Aperturen exakt über den Pads sitzen.

Da der Stencil größer als das 70 × 30 mm PCB ist, werden links/rechts bzw. ringsum **FR4-/PCB-Reststücke gleicher Dicke** als Shims aufgelegt. Damit kann der Stencil nicht an der PCB-Kante durchhängen.

Das PCB selbst wird mit kleinen Kapton-Streifen auf der Arbeitsunterlage gegen Verrutschen gesichert. Der Stencil wird an einer langen Seite mit Kapton als **Scharnier** befestigt. Dadurch kann er nach dem Druck nahezu senkrecht angehoben werden.

## 4. Stencil exakt ausrichten

1. Stencil trocken auflegen, noch keine Paste.
2. Unter heller Beleuchtung zuerst die kleinsten Pads ausrichten: AO3400A/SOT-23, Widerstände, kleine Kondensatoren.
3. Danach prüfen, ob auch SS34-/Dioden- und Elko-Pads mittig unter den Aperturen liegen.
4. Erst wenn die Aperturen rundum stimmen, die Scharnierseite mit 2–3 Kapton-Streifen befestigen.
5. Stencil einmal hochklappen und wieder absenken. Er muss exakt in dieselbe Position zurückkehren.

Bei sichtbarem Versatz nicht „später korrigieren“, sondern das Scharnier neu setzen.

## 5. Lötpaste aufrakeln

### 5.1 Paste auftragen

Einen dünnen, durchgehenden Paste-Strang vor die erste Reihe der Aperturen setzen. Mehr Paste ist nicht besser; sie muss lediglich genug Material liefern, um die Öffnungen vollständig zu füllen.

### 5.2 Rakelwinkel und Bewegung

- Rakel/alte feste Plastikkarte: ungefähr **45–60°**.
- Gleichmäßiger Druck.
- Ein ruhiger Druckzug über alle Aperturen.
- Falls sichtbar einzelne Öffnungen nicht gefüllt sind: maximal ein zweiter kontrollierter Zug.
- Nicht wiederholt hin- und herschmieren.

### 5.3 Stencil abheben

Nach dem Rakeln Stencil an der freien Seite anheben und möglichst **senkrecht vom PCB weg** schwenken. Nicht seitlich über die Paste ziehen.

Danach unter Vergrößerung prüfen:

- Pastendepots sauber begrenzt und ungefähr gleich hoch?
- Keine verschmierten Brücken zwischen Nachbarpads?
- Keine fehlenden Pads?
- Keine Paste außerhalb der Pads?

Wenn der Druck deutlich schlecht ist: nicht versuchen, ihn mit Pinzette „zu retten“. PCB mit IPA komplett reinigen und neu drucken. Das ist schneller und sicherer.

Stencil direkt nach dem Druck von beiden Seiten reinigen, solange die Paste noch weich ist.

## 6. Bauteile setzen

Das PCB liegt jetzt ohne Stencil auf einer ebenen Unterlage. Bauteile mit ESD-Pinzette auf die Paste setzen und nur leicht andrücken.

Empfohlene Reihenfolge:

1. kleine Widerstände und Keramikkondensatoren;
2. AO3400A Q1–Q4;
3. D1–D4 / D5;
4. größere SMD-Bauteile und Elkos, falls sie als SMD ausgeführt sind;
5. abschließende Orientierungskontrolle.

THT-Stecker, Stiftleisten, Kabel und andere große Kunststoffteile **erst nach dem Reflow** montieren.

### 6.1 Kritische Orientierungen IceDrone V3.4

- AO3400A: Orientierung exakt nach PCB-Silkscreen/Bestückungsdaten; Gate/Source/Drain nicht nach Gefühl drehen.
- D1–D4 SS34: Kathodenmarkierung/Band auf die vom Layout vorgesehene VBAT-Seite.
- D5: Polarität entsprechend V3.4-Schaltplan.
- C1/C2: Polarität kontrollieren, bevor Wärme auf die Platine kommt.

Vor dem Heizen ein Foto des fertig bestückten, noch kalten PCBs machen. Das hilft später beim Vergleich verschobener Bauteile.

## 7. Aufbau auf der YIHUA YH-853AAA

Die YIHUA hat laut Hersteller einen **120 × 120 mm Vorheizbereich** und einen separat geregelten Heißluftkanal. Das 70 × 30 mm IceDrone-PCB deshalb ungefähr mittig über dem Vorheizer positionieren.

YIHUA-Aufbau

**Realer Stationsaufbau:**

YIHUA YH-853AAA mit Spannvorrichtung

Die Heißluftdüse sitzt in deinem Aufbau gut erreichbar über der Platinenposition. Für den eigentlichen Reflow aber die Edelstahl-Schablone entfernen und möglichst auch unnötige massive Metallteile aus der direkten Heizzone nehmen. Der Luftstrom soll die kleinen Bauteile nicht wegschieben; die Düse deshalb nicht unnötig nahe an die Platine führen.

### 7.1 PCB-Abstand

PCB auf die vorgesehenen Halter/Abstandspunkte der Station bzw. auf temperaturbeständige kleine Supports legen. Es soll nicht schief liegen und nicht während des Reflows bewegt werden.

### 7.2 Thermoelement

Wenn vorhanden, ein K-Thermoelement mit Kapton auf einem repräsentativen GND-/Kupferbereich nahe der dichtesten SMD-Zone befestigen. Die Spitze soll möglichst Kontakt zum PCB haben, nicht frei in der Luft schweben.

## 8. Reflow-Profil als Startpunkt

Sn42Bi58 Profil

Die folgende YIHUA-Einstellung ist ein **praxisnaher Startpunkt**, kein kalibriertes Industrieprofil:

| Phase | Ziel am PCB | YIHUA Startwert | Richtwert |
|---|---:|---:|---:|
| 1. sanft vorwärmen | 70–90 °C | Preheater 90–100 °C | etwa 60–90 s |
| 2. soak | 105–125 °C | Preheater 110–120 °C | weitere 60–90 s |
| 3. Reflow starten | >138 °C | Heißluft 180–190 °C, niedrig | langsam kreisend |
| 4. Peak | ca. 155–165 °C | ggf. 190–205 °C Heißluft | nur so lange wie nötig |
| 5. Abkühlen | <138 °C | Heißluft weg, Preheater aus | PCB nicht bewegen |

### 8.1 Luftstrom

Niedrigen Luftstrom verwenden. Bei einer Prozent-Skala ungefähr **20–30%** als Ausgangspunkt. Der Luftstrom muss klein genug sein, dass 0603/0805-Komponenten nicht wandern. Ein eher breites 6–10-mm-Nozzle ist für gleichmäßiges Erwärmen günstiger als eine sehr kleine Düse mit lokalem Hotspot.

### 8.2 Abstand und Bewegung

Mit der Heißluft zunächst ungefähr **4–6 cm** Abstand halten und langsam kreisförmig über die bestückte Zone fahren. Nicht minutenlang auf einen SOT-23-Punkt halten.

### 8.3 Woran der Reflow sichtbar ist

Die Paste verändert sich typischerweise in Stufen:

1. zunächst grau/matt;
2. Flux wird dünn/flüssig;
3. Paste zieht sich plötzlich zusammen;
4. Lot wird metallisch/glänzend und benetzt Pad + Anschluss;
5. kleine Chips richten sich durch Oberflächenspannung leicht selbst aus.

Wenn **alle** Lötstellen sichtbar geflossen sind, noch kurz kontrollieren und dann die Heißluft entfernen. Nicht „zur Sicherheit“ lange weiterheizen.

### 8.4 Zeit oberhalb Liquidus

Für diese manuelle Methode keine exakte Sekunde erzwingen. Als Orientierung sollte die Zeit, in der die Lötstellen tatsächlich flüssig sind, eher im Bereich **einiger zehn Sekunden** liegen und nicht mehrere Minuten betragen. Das Chip-Quik-Referenzprofil für eine nahe verwandte Sn/Bi-Legierung erreicht etwa 165 °C Peak und bleibt nur begrenzt oberhalb 138 °C.

## 9. Abkühlen

Nach dem Reflow:

1. Heißluft wegnehmen.
2. Vorheizer ausschalten.
3. PCB **nicht bewegen**, solange das Lot noch flüssig sein könnte.
4. Natürlich auf deutlich unter 100 °C abkühlen lassen.
5. Keine Druckluft, kein Kühlspray, nicht auf kaltes Metall legen.

Die eutektische Legierung erstarrt beim Unterschreiten von 138 °C relativ abrupt. Trotzdem die Platine erst anfassen, wenn sie sicher handwarm ist.

## 10. Optische Kontrolle

Inspektion

Mit Lupe/Mikroskop jeden SMD-Pin und jedes Pad prüfen.

### Gut

- Bauteil mittig oder plausibel selbstzentriert;
- Lot hat Pad und Anschluss benetzt;
- keine Kugeln oder Brücken zwischen Netzen;
- Dioden/Elkos korrekt orientiert.

### Fehlerbilder

**Lötbrücke:** Lot verbindet zwei benachbarte Pins/Pads. Mit kompatiblem Flux + feiner Entlötlitze korrigieren.

**Tombstone:** Chip steht an einem Ende hoch. Bauteil erneut mit Sn42Bi58/Flux reflowen und flach positionieren.

**Unbenetzte/kalte Stelle:** matte körnige Insel oder Anschluss liegt sichtbar nur auf dem Lot. Mit Flux und moderater Wärme nacharbeiten.

**Zu viel Lot:** große Kugel, Bauteil schwimmt oder Pins verschwinden im Lot. Überschuss mit Entlötlitze abnehmen.

## 11. Elektrische Prüfung vor Versorgung

Noch ohne XIAO, Motoren, Sensoren und Akku:

1. Widerstand VBAT ↔ GND: **kein harter Kurzschluss**.
2. 5V ↔ GND: kein harter Kurzschluss.
3. 3V3 ↔ GND: kein harter Kurzschluss.
4. Q1–Q4: benachbarte SOT-23-Pins auf unbeabsichtigte Brücken prüfen.
5. D1–D4/D5 Polarität erneut kontrollieren.
6. C1/C2 Polarität erneut kontrollieren.
7. Sichtprüfung auf lose Lotkugeln.

Wenn ein Labornetzteil verfügbar ist, den ersten Einschaltversuch strombegrenzt durchführen. Propeller bleiben demontiert.

## 12. THT/Stecker erst nach dem SMD-Reflow

Erst wenn die SMD-Seite optisch und elektrisch plausibel ist:

- JST-/Motorstecker;
- Stiftleisten;
- externe Kabel;
- Batterie-Pigtail;
- Modulstecker

von Hand einlöten. Diese Teile müssen mechanisch entlastet werden. Bei Sn42Bi58 dürfen insbesondere Batterie-/Motorleitungen nicht ständig an der Lötstelle ziehen.

## 13. Nacharbeit

Für Nacharbeit an Sn42Bi58-SMD-Verbindungen:

- No-Clean-Flux sparsam einsetzen;
- moderate Temperatur verwenden;
- möglichst dasselbe bzw. kompatibles bleifreies Lot benutzen;
- vorhandenes Sn60PbCu2 nicht gezielt in die Sn42Bi58-Verbindung einmischen.

Für reine THT-Verbindungen, die elektrisch/mechanisch unabhängig von Sn42Bi58-Lötstellen sind, kann eine andere Lötlegierung technisch möglich sein. In einem Prototyp ist es dennoch übersichtlicher, die verwendeten Legierungen je Baugruppe klar zu dokumentieren.

## 14. Stencil reinigen und lagern

1. Paste grob mit fusselfreiem Tuch abnehmen.
2. Aperturen mit IPA reinigen.
3. Gegen Licht prüfen, ob keine Öffnung zugesetzt ist.
4. Stencil vollständig trocknen.
5. Flach und geschützt lagern; nicht knicken.

## 15. Schnellablauf für die Werkbank

**Reinigen → PCB fixieren → gleichdicke Shims → Stencil ausrichten → Kapton-Scharnier → Paste einmal rakeln → Stencil senkrecht abheben → Druck prüfen → Bauteile setzen → Vorheizen → niedriges Heißluft-Reflow → natürlich abkühlen → Mikroskop → Multimeter → erst danach THT und Strom.**

## 16. Reflow-Prozess als Bildstrecke

Die komplette Arbeitsfolge ist zusätzlich noch einmal bildgestützt zusammengefasst.

### 16.1 Gesamtablauf

Gesamtablauf Reflow

**Reinigen → Paste drucken → SMD bestücken → reflowen → optisch prüfen → elektrisch messen.**

### 16.2 Stencil und Pastendruck

Stencil-Setup

Der Stencil liegt beim Drucken plan auf; die Spannvorrichtung oder gleichdicke FR4-Shims verhindern ein Durchbiegen.

### 16.3 YIHUA-Aufbau

YIHUA Setup

Nur das **bestückte PCB ohne Stencil** wird vorgeheizt und anschließend mit niedrigem Heißluftstrom auf Reflow-Temperatur gebracht.

### 16.4 Temperaturverlauf Sn42Bi58

Sn42Bi58 Temperaturprofil

Der 138-°C-Liquidus wird nur kontrolliert überschritten; Zielbereich am PCB ist ungefähr 155–165 °C.

### 16.5 Kontrolle nach dem Reflow

Fehlerbilder Reflow

Erst nach Lupe/Mikroskop und Kurzschlussprüfung werden THT-Stecker bzw. externe Module angeschlossen.

### 16.6 Reale Fotos

| Stencil/Spannvorrichtung | YIHUA/Heißluftstation |
|---|---|
| Stencil real | YIHUA real |

> Das rechte Foto zeigt die mechanische Passprobe. Beim tatsächlichen Reflow ist der Stencil bereits entfernt.

## Quellen / Referenzen

- Indium Corporation, Solder Alloys: Bi58/Sn42 = 138 °C eutektisch: https://www.indium.com/products/alloys/solder-alloys/
- Indium Corporation, Low-Temperature Solder PDS: https://documents.indium.com/qdynamo/download.php?docid=3366
- Chip Quik, Low-Temperature Reflow Profile, ähnliches Sn42/Bi57.6/Ag0.4 als Profilreferenz: https://www.chipquik.com/datasheets/SMDLTLFP10.pdf
- YIHUA, YH-853AAA Spezifikation: 120 × 120 mm Preheater, 50–400 °C; Hot Air 100–480 °C: https://www.yihua-gz.com/products/yihua-853aaa-smd-soldering-desoldering-hot-air-gun-preheat-bga-rework-soldering-station

> Das Chip-Quik-Profil ist **nicht das Datenblatt der bestellten BEEYUIHF-Paste**, sondern eine technisch ähnliche Low-Temperature-Sn/Bi-Paste und dient nur als konservative Profilreferenz. Bei abweichenden Angaben auf der BEEYUIHF-Verpackung diese dokumentieren und das Profil entsprechend anpassen.

---
[← 10 - Perfboard V3.4 soldering](10_PERFBOARD_V34_SOLDERING_DE.md) | [Docs index](README.md)

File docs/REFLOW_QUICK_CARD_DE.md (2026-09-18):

# IceDrone V3.4 - Reflow Quick Card (Sn42Bi58)

**Paste:** Sn42Bi58, 138 °C eutektisch. **Stencil wird vor dem Heizen entfernt.**

1. PCB mit IPA reinigen, gleichdicke FR4-Shims um das PCB legen.
2. Stencil ausrichten, eine lange Seite mit Kapton als Scharnier fixieren.
3. Paste einmal bei ca. 45–60° gleichmäßig rakeln.
4. Stencil nahezu senkrecht abheben; Paste unter Lupe prüfen.
5. SMD setzen; Polaritäten Q/D/C kontrollieren. THT noch nicht montieren.
6. PCB mittig auf YIHUA-Vorheizer; Thermoelement wenn vorhanden.
7. Vorheizen: 90–100 °C Setpoint → etwa 70–90 °C PCB.
8. Soak: 110–120 °C Setpoint → etwa 105–125 °C PCB.
9. Heißluft 180–190 °C, niedriger Luftstrom, ca. 4–6 cm Abstand, kreisend.
10. Nur falls nötig auf 190–205 °C erhöhen. Ziel am PCB ca. 155–165 °C.
11. Sobald alle Lötstellen geflossen sind: Heißluft weg, Vorheizer aus.
12. Nicht bewegen bis unter 138 °C; natürlich abkühlen lassen.
13. Lupe/Mikroskop: Brücken, Tombstones, Polarität, Benetzung.
14. Multimeter: VBAT/GND, 5V/GND, 3V3/GND kein harter Kurzschluss.
15. Erst danach THT/Stecker und strombegrenzter Ersttest. Keine Propeller.

**Kein Sn60PbCu2 in bestehende Sn42Bi58-SMD-Lötstellen einmischen.**

## Reale Fotos

- [Stencil/Spannvorrichtung](assets/reflow_real_stencil_fixture_v34.jpg)
- [YIHUA-Aufbau](assets/reflow_real_yihua_setup_v34.jpg)

**Achtung:** Das YIHUA-Foto zeigt die mechanische Passprobe mit aufgelegtem Stencil. Vor dem tatsächlichen Heizen Stencil vollständig entfernen.

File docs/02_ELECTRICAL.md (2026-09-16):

[← Docs index](README.md)

# 02 - Electrical — IceDrone V3.4

V3.4 wiring overview

Authoritative machine-readable files:

- [`hardware/motor_stage_netlist.csv`](../hardware/motor_stage_netlist.csv)
- [`hardware/pinmap.csv`](../hardware/pinmap.csv)
- [`hardware/perfboard_v34_netlist.csv`](../hardware/perfboard_v34_netlist.csv)
- [`hardware/perfboard_v34_pin_matrix.csv`](../hardware/perfboard_v34_pin_matrix.csv)

> **Revision note:** V3.4 supersedes the earlier V1/V3.2/V3.3 electrical notes. In particular, M2 uses GPIO44/D7 instead of GPIO3, D1-D4 are SS34-class flyback diodes, the XIAO is powered from a regulated 5 V boost path, and the photographed VL6180X module has a verified seven-pin order.

## Power architecture

IceDrone V3.4 uses a raw **1S LiHV VBAT rail** for the brushed motors and the FH-1502 gimbal. A fully charged 1S LiHV cell can reach 4.35 V.

The XIAO ESP32-S3 Sense is **not** connected directly to raw VBAT in this revision. Use:

`VBAT → off-board 1S→5V boost → D5 Schottky → XIAO 5V`

The common ground is shared. The XIAO's regulated 3V3 output then powers the GY-91 and the VL6180X breakout.

### Required suppression and filtering

- C1: **470 µF / 10 V low-ESR** across VBAT/GND
- C2: **100 µF / 10 V low-ESR** across VBAT/GND
- C3: **100 nF ceramic** from VBAT_ADC to GND, in parallel with R10
- D1-D4: **SS34-class ≥3 A Schottky** flyback diodes
- one additional **100 nF ceramic directly across each motor's terminals**
- short, wide VBAT/GND/motor-current wiring
- twisted motor wire pairs where practical
- keep ADC and I2C wiring away from motor drain/PWM wiring

## Motor driver channel

Each motor is low-side switched by an AO3400A:

```mermaid
flowchart LR
    VBAT --> MOTOR["8520 motor"] --> DRAIN["Motor− / MOSFET drain"]
    DRAIN --> Q["AO3400A"] --> GND
    DRAIN --> DIODE["SS34 ≥3 A<br/>anode = drain<br/>cathode/band = VBAT"] --> VBAT
    GPIO -->|"100 Ω"| GATE["MOSFET gate"]
    GATE -->|"100 kΩ"| GND
```

The gate pulldown is mandatory because it holds the MOSFET off while the ESP32 GPIO is high impedance during boot.

### AO3400A pinout

For the SOT-23 AO3400A package:

- pin 1 = Gate
- pin 2 = Source
- pin 3 = Drain

On perfboard use a SOT-23 adapter or very short dead-bug leads. Do not infer the electrical node from the physical drawing alone; follow the netlist.

## GPIO map

| Function | XIAO pin / GPIO | Notes |
|---|---|---|
| M1 rear-left | D3 / GPIO4 | PWM |
| M2 rear-right | **D7 / GPIO44** | PWM; changed from GPIO3 in V3.4 |
| M3 front-right | D5 / GPIO6 | PWM |
| M4 front-left | D4 / GPIO5 | PWM |
| Battery ADC | D0 / GPIO1 | 100k/100k divider + 100 nF filter |
| I2C SDA | D1 / GPIO2 | GY-91 + VL6180X |
| I2C SCL | D6 / GPIO43 | GY-91 + VL6180X |
| Gimbal PWM | GPIO42 test pad | conflicts with Sense PDM microphone clock |

GPIO3 is intentionally left unused in V3.4. The Sense camera GPIO set and microSD GPIO7/8/9/21 are preserved.

## I2C requirement

Because GPIO5 and GPIO6 are motor PWM outputs, do not rely on the XIAO default I2C pins.

Firmware must explicitly initialize:

```cpp
Wire.begin(2, 43);
```

## Battery measurement

R9 and R10 form a 100k/100k divider:

`VBAT → R9 → VBAT_ADC → R10 → GND`

C3 = 100 nF is placed in parallel with R10 to suppress motor brush noise.

Nominally:

`V_ADC = VBAT / 2`

At 4.35 V battery voltage the ADC node is about 2.175 V.

In firmware start with:

`VBAT = V_ADC * 2.0`

and calibrate against a multimeter.

## VL6180X — photographed module

With the actual module front side visible, text upright and header at the bottom, the physical pin order is:

`VIN | 2V8 | GND | GPIO | SHDN | SCL | SDA`

V3.4 uses:

- VIN → XIAO 3V3
- GND → common GND
- SCL → GPIO43 / D6
- SDA → GPIO2 / D1
- SHDN → optional / normally NC
- 2V8 → NC
- GPIO → NC

Do **not** connect the module's 2V8 output to the XIAO 3V3 rail.

## Perfboard coordinate convention

The 70×30 mm perfboard uses this fixed convention:

| View | left → right | top → bottom |
|---|---|---|
| component side | A B C D E F G H I J | 1…24 |
| solder side | J I H G F E D C B A | 1…24 |

- `A1-A24` = VBAT
- `J1-J24` = GND
- `E12` = unused

The detailed construction guide and rear-view solder map are in [10 - Perfboard V3.4 soldering](10_PERFBOARD_V34_SOLDERING_DE.md).

## Current-separation rule

Dupont/breadboard jumper wires are only for low-current module and signal connections.

Do **not** route battery or 8520 motor current through Dupont jumpers. Use BT2.0/JST-XH or equivalent appropriately rated wiring/connectors for battery and motor current.

## Before connecting the XIAO

1. continuity-test VBAT-to-GND; no hard short may be present;
2. verify every MOSFET source is at GND;
3. verify each drain is only on its own motor−/flyback node;
4. verify D1-D4 cathode bands point toward VBAT;
5. verify D5 cathode points toward XIAO 5V;
6. verify C1/C2 polarity;
7. verify raw VBAT has no direct path to XIAO 5V;
8. verify boost output before connecting the XIAO;
9. first power-up with propellers removed and preferably with a current-limited bench supply.

---
[← 01 - BOM](01_BOM.md) | [Docs index](README.md) | Next: [03 - Mechanical →](03_MECHANICAL.md)

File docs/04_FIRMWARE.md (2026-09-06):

[← Docs index](README.md)

# 04 - Firmware

## Strategy

The flight-critical code should track Open32Drone rather than being reimplemented from scratch in this repo. The current upstream project documents:

- XIAO ESP32-S3 Sense
- ESP32 Arduino Core 3.3.6
- 300 Hz flight-critical main loop
- 10 kHz / 10-bit motor PWM
- optional QVGA MJPEG stream in a separate low-priority task
- MAVLink v2 over UDP 14550
- Wi-Fi AP fallback
- current motor GPIOs 4/3/6/5
- IMU I2C on GPIO2/43

```mermaid
flowchart LR
    subgraph XIAO["XIAO ESP32-S3 Sense"]
        FC["Flight-critical loop<br/>300 Hz"] --> PWM["4x motor PWM<br/>10 kHz / 10-bit"]
        CAM["Camera task<br/>low priority"] --> MJPEG["QVGA MJPEG stream"]
    end
    FC <-->|"UDP 14550<br/>MAVLink v2"| GCS["GCS / phone client"]
    MJPEG -->|"HTTP, 1 viewer max"| Viewer["Video viewer"]
```

Fetch Open32Drone from its upstream repository (see `docs/SOURCES.md`) and record the exact revision used in your build log, e.g. `git -C vendor/open32drone rev-parse HEAD`.

This repo vendors it as the `vendor/open32drone` git submodule and keeps the V1 config deltas below as a patch rather than edits to the submodule itself — see [`firmware/open32drone/README.md`](../firmware/open32drone/README.md) for the exact build/flash commands and the 2026-09-06 USB-only smoke-test log (camera, Wi-Fi AP, MAVLink transport confirmed working without IMU/motors/battery wired).

## Arduino build settings

For the current upstream documentation:

- Board: `XIAO_ESP32S3`
- ESP32 Arduino Core: 3.3.6
- OPI PSRAM: enabled
- flash mode: DIO as documented by upstream
- partition: upstream's documented 8 MB A/B/default partition
- serial monitor: 115200

Do not casually update the ESP32 core on a flight-tested build. Re-run all prop-off and tethered tests after framework upgrades.

## Local V1 choices

The intended V1 policy, to be applied as Open32Drone configuration settings:

- camera enabled
- QVGA
- one viewer maximum
- MJPEG quality starting point 18
- MAVLink port 14550
- optical flow disabled for V1
- SBUS disabled for V1
- battery divider factor 2.0
- low-voltage warning/landing thresholds as initial values only

These are a project manifest, not a guaranteed drop-in upstream header, because upstream changes. Apply the corresponding settings to the current Open32Drone configuration and document the resulting diff in your fork.

## Video

Use the upstream bounded background stream. Keep these design rules:

1. control loop wins over video;
2. one video client maximum;
3. QVGA first;
4. drop frames instead of growing queues;
5. if loop timing degrades, reduce frame rate/quality before touching flight-control rates;
6. never use the SD card in V1; D7-D10 are more useful as expansion/RC pins and the card adds I/O load.

The stream URL in current Open32Drone documentation is `http://192.168.4.1/stream` when using its default AP address.

## MAVLink / control

Default UDP port is 14550. For first testing, use a single GCS/phone client. Do not fly solely by looking at MJPEG video until measured end-to-end latency is acceptable; ESP32 MJPEG is suitable for inspection and slow FPV, not low-latency racing.

## Bench-test firmware

[`firmware/bench_test/main.cpp`](../firmware/bench_test/main.cpp) is intentionally **not a flight controller**. It performs three safe integration checks:

- initializes the XIAO Sense camera and captures a JPEG;
- prints IMU values if a supported test IMU is connected;
- pulses one selected motor at low duty for 250 ms.

Build with PlatformIO:

```bash
cd firmware/bench_test
pio run -t upload
pio device monitor
```

**Remove all propellers before running it.**

Note: the bench sketch uses Adafruit MPU6050 for a simple library-based smoke test. If the final board uses GY-91/MPU9250, validate it with Open32Drone's actual IMU backend as part of the upstream bring-up.

---
[← 03 - Mechanical](03_MECHANICAL.md) | [Docs index](README.md) | Next: [05 - Build and Test →](05_BUILD_AND_TEST.md)

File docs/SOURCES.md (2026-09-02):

[← Docs index](README.md)

# Sources

Checked 2026-09-02.

## Core projects

- Open32Drone repository: https://github.com/npu-ius-lab/open32drone
- Open32Drone tutorial: https://github.com/npu-ius-lab/open32drone/blob/main/tutorial.md
- Open32Drone license: Apache-2.0
- Flix: https://github.com/okalachev/flix
- Flix user projects / ESP32-S3-CAM streaming: https://github.com/okalachev/flix/blob/master/docs/user.md
- ESP-FLY: https://github.com/Seeed-Projects/Co-Create_ESP-FLY

## Seeed documentation

- XIAO ESP32-S3 series: https://wiki.seeedstudio.com/xiao_esp32s3_getting_started/
- XIAO ESP32-S3 pin multiplexing: https://wiki.seeedstudio.com/xiao_esp32s3_pin_multiplexing/

Key facts verified from current documentation:

- XIAO Sense current camera is OV3660; OV2640 has been discontinued for current production.
- 8 MB PSRAM / 8 MB flash.
- board footprint approximately 21×17.8 mm; Sense stack about 15 mm high.
- camera uses GPIO10-18, 38-40, 47, 48 internally.
- Open32Drone uses GPIO4/3/6/5 for four 10 kHz motor PWM outputs and GPIO2/43 for I2C.
- current Open32Drone docs describe a 300 Hz flight-critical loop and optional low-priority QVGA MJPEG service.
- Open32Drone specifies 8520 1.0-mm-shaft motors and 76-mm props, with target takeoff mass 60-80 g.

## Purchase verification

- Botland XIAO ESP32-S3 Sense, index SEE-22926, listed at €15.90 and available/24 h when checked: https://botland.de/wifi-und-bt-module-esp32/22926-seeed-xiao-esp32-s3-sense-kamera-kit-mit-ov3660-wifi-bluetooth-seeedstudio-113991115.html
- Reichelt AO3400A product result: AO3400A, 30 V N-MOSFET SOT-23, around €0.18 at check time.
- Hobbydrone.cz EMAX 650 mAh 1S LiHV PH2.0, >20 in stock when checked: https://www.hobbydrone.cz/de/tinyhawk-1s-120c-hv-650mah-lipo/
- Electrapac 76 mm two-blade 1.0-mm-hole propellers: https://www.electrapac.com/product/2-Pcs-76mm-Propeller-For-1020-8520-Coreless-motor
- Amazon.de marketplace product search returned XIAO Sense, 8520 motors, GY-91 and AO3400A options, but marketplace seller/variant availability is not stable enough to pin as the sole source.

## Verification policy

A URL in this document records what was checked, not a guarantee of future availability. Before ordering, confirm the shaft diameter, connector, camera version, dimensions and stock state on the seller's current page.

---
[← 09 - Amazon.de Order List](09_AMAZON_ORDER_LIST_DE.md) | [Docs index](README.md)

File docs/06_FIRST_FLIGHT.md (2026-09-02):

[← Docs index](README.md)

# 06 - First Flight

## Environment

Use a clear, low-risk test area with no people, animals, glass, loose cables or fragile objects in the propeller plane. For the very first lift-off, a large empty indoor space or calm outdoor area is preferable to a small room.

```mermaid
flowchart TD
    P1["Phase 1: prop direction check"] --> P2["Phase 2: 5 cm hop"]
    P2 --> P3["Phase 3: 20-30 cm hover"]
    P3 --> P4["Phase 4: video on"]
    P4 --> OK(("V1 mechanically/electrically validated"))
```

## Phase 1 - prop direction check

Fit props according to the expected Quad-X direction. Arm at the lowest possible output while restraining the frame safely. Immediately disarm if the craft pushes sideways, flips, or any prop loosens.

## Phase 2 - 5 cm hop

Do not attempt a long hover first. Perform a 5 cm hop lasting <1 s. Observe:

- does it remain approximately level?
- does yaw immediately run away?
- does one corner lift earlier?
- is there violent high-frequency oscillation?

Correct mechanical/axis/motor issues before changing PID gains.

## Phase 3 - 20-30 cm hover

Once hop behavior is correct, hover at 20-30 cm for 5-10 s. Land and inspect motor temperatures and frame/motor retention.

## Phase 4 - video on

Repeat the stable hover with the MJPEG stream enabled. Compare:

- flight-loop frequency
- control feel
- Wi-Fi packet loss
- video frame rate
- battery sag

If control quality degrades, lower video load first.

## Initial acceptance criteria

A V1 build is considered mechanically/electrically validated when it can:

- arm/disarm reliably;
- hover for 30 s without divergent oscillation;
- maintain control with the video stream active;
- recover cleanly from modest stick inputs;
- land before battery reaches the configured low-voltage threshold;
- complete 3 flights without motor, frame or camera-mount loosening.

## Do not tune around faults

Common non-PID faults that look like bad tuning:

- IMU not exactly aligned
- loose motor in cup
- bent prop
- wrong prop direction
- wrong motor mapping
- camera/board mass far off center
- battery moving in cradle
- motor electrical noise causing I2C errors
- insufficient battery discharge capability

---
[← 05 - Build and Test](05_BUILD_AND_TEST.md) | [Docs index](README.md) | Next: [07 - Safety and Legal →](07_SAFETY_AND_LEGAL_DE.md)

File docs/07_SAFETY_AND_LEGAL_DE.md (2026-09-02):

[← Docs index](README.md)

# 07 - Safety and Legal (DE/EU)

This section is a practical engineering reminder, not legal advice. Re-check official rules before operation because requirements can change.

## Workshop safety

- Remove props for all bench firmware and electronics tests.
- Treat 1S LiPo/LiHV packs as high-current sources; a short circuit can cause fire.
- Use a charger explicitly supporting the chemistry and final voltage. A LiHV 3.8 V nominal pack may be charged to 4.35 V only with a LiHV-capable charger.
- Do not charge unattended or use a swollen/damaged cell.
- Secure the U.FL antenna before applying sustained Wi-Fi load.
- After crashes, inspect motor cups, arms, battery and propellers before re-arming.

## Operating category

The design target is far below 250 g. A privately built UAS below 250 g can generally be operated in the EU Open category under the applicable A1 conditions, subject to all geographic-zone and operational restrictions. A camera can trigger operator-registration requirements even below 250 g unless an exemption applies. Liability insurance remains a separate German requirement for model aircraft/UAS operation.

Use the official EASA and German authority pages as the authoritative source at time of flight.

Useful starting points:

- EASA drones FAQ: https://www.easa.europa.eu/en/the-agency/faqs/drones-uas
- German UAS portal / geographic zones: https://dipul.de/

## Wi-Fi/video

The XIAO uses 2.4 GHz Wi-Fi. Keep the design within the module's certified radio configuration and antenna arrangement; do not add unapproved high-power RF amplifiers.

---
[← 06 - First Flight](06_FIRST_FLIGHT.md) | [Docs index](README.md) | Next: [08 - Troubleshooting →](08_TROUBLESHOOTING.md)

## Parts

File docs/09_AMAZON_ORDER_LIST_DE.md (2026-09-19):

[← Docs index](README.md)

# 09 - Amazon.de Order List (DE)

Convenience shopping list originally collected on 2026-09-02. This is a **dated sourcing snapshot**, not the electrical specification.

> **V3.4 IMPORTANT:** The authoritative electrical requirements are now [`01_BOM.md`](01_BOM.md), [`02_ELECTRICAL.md`](02_ELECTRICAL.md) and the [V3.4 perfboard guide](10_PERFBOARD_V34_SOLDERING_DE.md). Do not copy older SS14/6.3-V/direct-XIAO-power assumptions from a historical shopping link. V3.4 uses **SS34-class ≥3 A motor flyback diodes**, **C1 470 µF/10 V**, **C2 100 µF/10 V**, and a **1S→5 V boost + D5** for XIAO power.

> Marketplace listings, prices, stock and even the shipped variant behind a given listing change frequently. Open every listing and verify the exact electrical/mechanical variant before ordering.

| Part | Qty | Example/source note | V3.4 verify before ordering |
|---|---:|---|---|
| Seeed XIAO ESP32-S3 Sense | 1 | Amazon/Seeed distributor | Sense version; actual camera module may be OV2640 or OV3660 |
| GY-91 MPU9250+BMP280 | 1 | Amazon marketplace | Confirm MPU9250/actual IMU variant, not an MPU6050 clone |
| VL6180X breakout | 1 | Existing photographed module / marketplace | 7-pin order must match `VIN,2V8,GND,GPIO,SHDN,SCL,SDA` |
| 8520 coreless motor, 1.0 mm shaft | 6 (4 + 2 spares) | RC/Amazon supplier | **1.0 mm shaft**; 8.5×20 mm class |
| 75/76 mm 2-blade props, 1.0 mm bore | 2 sets | RC supplier | Exact bore and matched CW/CCW set |
| 1S LiHV battery | 2 | BETAFPV/RC supplier | 3.8 V nominal, 4.35 V full; BT2.0 preferred for this build |
| 1S→5 V boost module | 1 | Electronics/RC supplier | ≥0.7 A continuous, ≥1 A transient recommended; verify 5 V output before XIAO |
| AO3400A N-MOSFET, SOT-23 | 4 + spares | Reichelt/standard distributor | Pin 1 Gate, 2 Source, 3 Drain |
| **SS34-class Schottky** | 4 + spares | standard electronics distributor | **≥3 A**; motor flyback; band/cathode toward VBAT |
| D5 Schottky | 1 + spare | SS14/1N5819W class acceptable here | ≥1 A; boost-to-XIAO isolation, not a motor flyback diode |
| 100 Ω resistor | 4 + spares | 0603/0805 or THT | gate series resistor |
| 100 kΩ resistor | 6 + spares | 0603/0805 or THT | four gate pulldowns + ADC divider |
| **470 µF low-ESR capacitor** | 1 + spare | standard distributor | **10 V**, C1, polarity |
| **100 µF low-ESR capacitor** | 1 + spare | standard distributor | **10 V**, C2, polarity |
| 100 nF ceramic | 5 + spares | standard distributor | one ADC filter + one directly across each motor |
| BT2.0 pigtail | 1 + spare | RC supplier | 20–22 AWG preferred; verify polarity |
| JST-XH/equivalent motor connectors | 4 | electronics supplier | current-capable; no Dupont for motor current |
| silicone wire | assorted | electronics supplier | 28–30 AWG signals; **22–24 AWG or suitably rated wire for battery/motor current** |
| 1S LiHV charger | 1 | RC supplier | must support the actual 4.35 V LiHV pack |
| Perfboard | 1 | electronics supplier | **70×30 mm**, 2.54 mm pitch for the V3.4 prototype |

## What was actually ordered / physically observed

- **Battery connector:** BT2.0 was selected for the current 1S LiHV setup. Verify polarity with a multimeter before first connection.
- **XIAO ESP32-S3 Sense:** the received camera module was observed as OV2640. The camera backend/bench testing should therefore be validated against the actual board rather than relying on a marketplace title.
- **Motors:** sourced as 8520-class motors with 75 mm props; shaft diameter remains a mandatory physical check before final assembly.
- **VL6180X:** the physical module was photographed and its seven-pin order was incorporated into V3.4. `2V8` and `GPIO` remain unused; `VIN` is supplied from XIAO 3V3.

## Why exact marketplace links are intentionally not authoritative

Marketplace sellers and variants change. A listing that was correct on the search date can later ship a different connector, motor shaft, camera module or component package. The repository therefore separates:

1. **electrical/mechanical requirements** — authoritative in chapters 01/02/10 and `hardware/`;
2. **shopping links** — disposable convenience references that must be re-checked at purchase time.

For the current build, always resolve conflicts in favor of the V3.4 electrical documentation.

---
[← 08 - Troubleshooting](08_TROUBLESHOOTING.md) | [Docs index](README.md) | Next: [10 - Perfboard V3.4 soldering →](10_PERFBOARD_V34_SOLDERING_DE.md)

## SMD-Sortiment für den V3.4-PCB-Erstaufbau (2026-09-19)

Für den ersten Reflow ist die **0603-Version** des **JTAREA 6390pcs SMD Electronic Component Assortment** deutlich geeigneter als die 0805-Version. Laut aktueller Produktbeschreibung enthält das 0603-Set unter anderem:

- 1%-Widerstände 0603 einschließlich **100 Ω** und **100 kΩ**;
- 0603-Keramikkondensatoren einschließlich **100 nF**;
- Schottky-Dioden **1N5822 / SS34, SMA** (für D1-D4 geeignet);
- **1N5819 / SS14, SMA** sowie weitere Dioden;
- zusätzliche Transistoren, ICs, Induktivitäten und LEDs als Werkstattbestand.

Damit deckt ein Set R1-R10, C3 und D1-D4 ab. **Nicht abgedeckt** sind der für D5 vorgesehene **1N5819W/B5819W im SOD-123-Footprint** sowie die beiden großen SMD-Elkos C1/C2.

Für D5 separat nach **1N5819W oder B5819W, 1 A / 40 V, SOD-123** suchen. Die bereits vorhandenen SS14 im SMA-Gehäuse sind dafür mechanisch zu groß.

Für C1/C2 sind allgemeine Elektrolyt-Sortimente nur dann sinnvoll, wenn Durchmesser/Land-Pattern passen. Viele 470-µF/16-V-Sortimentsteile sind 10 mm groß und passen nicht auf das geplante C1-Footprint. Für den Erstaufbau deshalb C1/C2 footprintgenau beschaffen.

## Amazon-Sets für D5 und C1/C2 (Stand 2026-09-19)

### C1 + C2 gemeinsam in einem SMD-Elko-Sortiment

Ein auf Amazon.de gefundenes **400 Stück / 24 Werte SMD-Aluminium-Elko-Sortiment 1 µF–1000 µF** ist für die beiden Bulk-Kondensatoren besonders interessant. Die zugehörige Stückliste nennt ausdrücklich:

- **100 µF / 16 V, 6.3 × 5.4 mm** → passend zur C2-Gehäuseklasse.
- **470 µF / 16 V, 8 × 10.5 mm** → passend zur C1-Gehäuseklasse.

Damit können C1 und C2 aus **einem** Sortiment bestückt werden. Beim Wareneingang trotzdem Durchmesser und Polaritätsmarkierung gegen das PCB prüfen.

Die kleinere 95-Stück/8-Werte-16-V-SMD-Elko-Box enthält zwar ebenfalls 100 µF und 470 µF, veröffentlicht aber nicht zuverlässig die Gehäusemaße je Wert. Für das IceDrone-PCB ist deshalb das 400er/24-Werte-Set mit expliziten Abmessungen vorzuziehen.

### D5

Für D5 wurde auf Amazon.de ein **VGOL 100er-Pack 1N5819, SOD-123, 1 A / 40 V** gefunden. Vor Checkout ausdrücklich kontrollieren, dass im Angebot **SOD-123** und nicht DO-41, SMA oder SOD-323 ausgewählt ist.

Ein sinnvolles gemeinsames Sortiment, das gleichzeitig den SOD-123-D5 **und** die beiden großen SMD-Aluminium-Elkos in den benötigten Gehäusegrößen enthält, wurde nicht gefunden. Für die sichere mechanische Passung bleiben daher zwei Bestellpositionen sinnvoll: 1× SMD-Elko-Sortiment + 1× SOD-123-Schottky-Pack.

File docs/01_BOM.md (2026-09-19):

[← Docs index](README.md)

# 01 - Bill of Materials (BOM)

**Current electrical revision:** IceDrone V3.4  
**Updated:** 2026-09-18

Machine-readable hardware version: [`bom/bom.csv`](../bom/bom.csv).  
Dedicated PCB-reflow tooling/consumables: [`bom/reflow_bom.csv`](../bom/reflow_bom.csv).  
Current first-article SMD inventory / missing-parts list: [`bom/pcb_smd_inventory_v34.csv`](../bom/pcb_smd_inventory_v34.csv).

> The older V1 sourcing list contained SS14 motor flyback diodes, 6.3 V bulk capacitors and a direct XIAO battery-input concept. Those values are **obsolete for V3.4**. Use the V3.4 requirements below.

## Core V3.4 hardware

| Qty | Category | Part | V3.4 requirement | Critical check |
|---:|---|---|---|---|
| 1 | compute | Seeed XIAO ESP32-S3 Sense | Sense camera version | external 5 V supply path; not raw LiHV |
| 1 | sensor | GY-91 MPU9250+BMP280 | 3.3 V I2C | verify actual IMU variant |
| 1 | sensor | VL6180X breakout | photographed 7-pin module | pin order VIN,2V8,GND,GPIO,SHDN,SCL,SDA |
| 1 | actuator | FH-1502 gimbal/servo | PWM | GPIO42; PDM microphone unavailable |
| 4 + spares | propulsion | 8520 brushed motor | 8.5×20 mm, 3.7 V, 1.0 mm shaft | shaft size mandatory |
| 1 set + spares | propulsion | 75–76 mm propellers | 1.0 mm bore, matched CW/CCW | verify bore and rotation |
| 1–2 | power | 1S LiHV battery | 3.8 V nominal, max 4.35 V | LiHV-capable charger |
| 1 | power | 1S→5 V boost | ≥0.7 A continuous, ≥1 A transient recommended | XIAO supply path |
| 4 | electronics | AO3400A | N-MOSFET, SOT-23 | pin orientation critical |
| 4 | electronics | **SS34-class Schottky** | **≥3 A** | flyback; cathode/band to VBAT |
| 1 | electronics | D5 Schottky | ≥1 A, e.g. SS14/1N5819W class | cathode to XIAO 5V |
| 4 | electronics | 100 Ω | gate series resistor | one per MOSFET |
| 6 | electronics | 100 kΩ | 4 pulldowns + 2 ADC divider | correct values |
| 1 | electronics | **470 µF / 10 V low-ESR** | C1 | polarity |
| 1 | electronics | **100 µF / 10 V low-ESR** | C2 | polarity |
| 5 | electronics | 100 nF ceramic | C3 + 4 motor-terminal caps | motor caps directly at motor |
| 1 | power | BT2.0 pigtail | 20–22 AWG preferred | polarity |
| 4 | power | JST-XH/equivalent 2-pin motor connector | current-capable | no Dupont for motor current |
| 1 | prototype | 70×30 mm perfboard | 2.54 mm pitch | V3.4 coordinate system |

## Vorhandenes Aluminium-Elko-Kit (Werkstattbestand)

Auf dem am 2026-09-19 fotografierten **925Pcs / 36 Values Aluminum Capacitor Box Kit** sind unter anderem folgende für V3.4 interessante radiale THT-Elkos vorhanden:

| Kit-Wert | Abmessung laut Box | Bezug zu V3.4 | Bewertung |
|---|---:|---|---|
| 470 µF / 10 V | 6×7 mm | entspricht C1 elektrisch | **nicht als finaler C1**: radial/THT; Low-ESR nicht spezifiziert |
| 100 µF / 25 V | 6×12 mm | möglicher C2-Wert elektrisch | **nicht als finaler C2**: radial/THT; Low-ESR nicht spezifiziert |
| 100 µF / 35 V | 6×7 mm | möglicher C2-Wert elektrisch | **nicht als finaler C2**: radial/THT; Low-ESR nicht spezifiziert |

Die höhere Spannungsfestigkeit bei C2 wäre elektrisch unkritisch; entscheidend sind aber **Low-ESR-Eigenschaft und SMD-Footprint-Kompatibilität**. Die V3.4-PCB-Anforderung bleibt deshalb:

- **C1:** 470 µF / mindestens 10 V, low-ESR, SMD-Aluminium-Elko; bevorzugt Panasonic **EEE-FP1A471AP** (ca. Ø8×10.2 mm; passendes SMD-Land-Pattern vorausgesetzt).
- **C2:** 100 µF / mindestens 10 V, low-ESR, SMD-Aluminium-/Polymer-Elko; mechanisch zum tatsächlich gefertigten PCB-Footprint passend.

Die radialen Kit-Elkos können bei Bedarf als **temporäre Bench-/Messkondensatoren** mit sehr kurzen Leitungen verwendet werden, sind aber kein 1:1-Ersatz für die vorgesehenen SMD-Bauteile auf dem Flug-PCB.

## PCB first-article / reflow BOM

The custom **70×30 mm PCB and stencil are now physically available**. The dedicated assembly list is [`bom/reflow_bom.csv`](../bom/reflow_bom.csv) and includes:

- YIHUA YH-853AAA preheater/hot-air station;
- V3.4 stainless stencil;
- Sn42Bi58 low-temperature solder paste, 138 °C eutectic;
- Kapton tape for the stencil hinge / thermocouple;
- same-thickness FR4/old-PCB shims for an oversized stencil;
- squeegee, ESD tweezers and magnification;
- 99% IPA + lint-free wipes;
- optional but strongly recommended K-type thermocouple;
- no-clean flux and fine desoldering braid for rework.

See [11 - PCB Reflow Sn42Bi58](11_REFLOW_SN42BI58_DE.md) before applying paste.

## AO3400A

The V3.4 motor stage uses AO3400A because it has low RDS(on) specified at low gate voltage. For the SOT-23 package use the manufacturer's pinout:

- pin 1 = Gate
- pin 2 = Source
- pin 3 = Drain

For a perfboard prototype use a SOT-23 adapter or very short dead-bug leads.

## Power components

### D1-D4

Motor flyback diodes are **SS34-class ≥3 A Schottky** parts in V3.4. Prefer a **3 A / 40 V SMA (DO-214AC)** device such as SS34 or B340A-class. The earlier SS14/1 A choice is **not suitable for D1-D4** in V3.4.

The previously considered Amazon listing **“Chanzon SS14, 1 A / 40 V, SMA (DO-214AC)”** is currently unavailable and, independently of availability, is no longer the correct motor-flyback choice for this revision. SS14 remains electrically acceptable only for the lower-current **D5** isolation position, provided its footprint matches.

### C1 / C2

The available **BEEYUIHF 925 pcs / 36-value low-ESR electrolytic assortment** contains suitable electrical values for the two bulk capacitors:

- **C1:** use **470 µF / 10 V** from the kit.
- **C2:** the kit does not list 100 µF / 10 V, but does contain **100 µF / 16 V**. That is electrically acceptable and provides more voltage margin than required.

The manufacturer lists the kit as radial-leaded aluminum electrolytics. Therefore the **mechanical footprint must be checked on the manufactured V3.4 PCB before installation**. If the PCB uses an SMD aluminum-electrolytic footprint, these radial parts are not drop-in replacements and must not be forced onto the SMD pads.

The kit is **not a source for C3 or the four 100 nF motor capacitors**. Those are ceramic/non-electrolytic parts and remain separate BOM items.

### D5 and boost converter

Raw 1S LiHV can reach 4.35 V. V3.4 therefore feeds the XIAO through:

`VBAT → 1S→5V boost → D5 Schottky → XIAO 5V`

Do not connect raw LiHV directly to XIAO 5V/BAT in this hardware revision.

## Connectors and wire

Use Dupont/breadboard jumpers only for low-current signals/modules:

- XIAO signal lines
- GY-91
- VL6180X
- gimbal signal
- boost control/sense wiring

Battery and motor current must use suitable wire and connectors such as BT2.0/JST-XH or equivalent.

## Perfboard prototype

The temporary prototype uses a **70×30 mm** perfboard. See:

- [02 - Electrical](02_ELECTRICAL.md)
- [05 - Build and Test](05_BUILD_AND_TEST.md)
- [10 - Perfboard V3.4 soldering](10_PERFBOARD_V34_SOLDERING_DE.md)

The custom manufactured PCB is intended to replace the perfboard after first-article validation.

## Sourcing note

`09_AMAZON_ORDER_LIST_DE.md` is a dated marketplace sourcing snapshot. Electrical requirements in this BOM and in `02_ELECTRICAL.md` take precedence if the shopping list contains an older value.

---
[← Docs index](README.md) | Next: [02 - Electrical →](02_ELECTRICAL.md)

## Manufactured PCB verification (Eurocircuits first article)

The actual V3.4 B70 production documentation confirms a 70 × 30 mm, 2-layer FR-4 bare PCB with lead-free finish and electrical test. The production top-view also confirms the intended package families: AO3400A in SOT-23, D1-D4 in SMA/DO-214AC, a smaller D5 footprint in the SOD-123 class, 0603-class small passives, and two SMD aluminum-electrolytic can footprints for C1/C2 (approximately 8 mm and 6.3 mm body classes). Radial electrolytics from the BEEYUIHF kit are therefore not drop-in replacements for C1/C2.

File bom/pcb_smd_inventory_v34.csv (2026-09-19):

designators | qty | required_part | required_value | pcb_package | status_2026-09-19 | action | notes
Q1-Q4 | 4 | AO3400A | 30V N-MOSF | SOT-23 | CONFIRMED_AVAILABLE | none | Amazon A09T/AO3400(A) parts physically available; verify orientation before placement
D1-D4 | 4 | B340A-13-F / SS34-class | 3A 40V Schottky | SMA (DO-214AC) | MISSING | ORDER | Do not use SS14 1A here; buy at least 10 pcs for spares
D5 | 1 | 1N5819W / 1N5819HW / B5819W | 1A 40V Schottky | SOD-123/SOD-123FL class | AMAZON_OPTION_FOUND | ORDER | Amazon.de option found 2026-09-19: VGOL 100-pack 1N5819 SOD123 1A 40V; confirm listing still says SOD123 before checkout
R1-R4 | 4 | RC0603FR-07100RL | 100 ohm 1% | 0603 | UNCONFIRMED | ORDER_IF_NOT_IDENTIFIED | Buy 10-20 pcs; non-polar
R5-R10 | 6 | RC0603FR-07100KL | 100 kohm 1% | 0603 | UNCONFIRMED | ORDER_IF_NOT_IDENTIFIED | Buy 10-20 pcs; non-polar
C3 | 1 | CC0603KRX7R9BB104 | 100 nF 50V X7R | 0603 | MISSING | ORDER | Buy 10-20 pcs; non-polar
C1 | 1 | 470 uF >=10V SMD electrolytic | 470 uF 16V | SMD aluminum can 8x10.5mm | AMAZON_SET_OPTION_FOUND | ORDER_SET | 400pcs/24-value SMD aluminum electrolytic assortment includes 470uF 16V 8x10.5mm; footprint class matches production preview
C2 | 1 | 100 uF >=10V SMD electrolytic | 100 uF 16V | SMD aluminum can 6.3x5.4mm | AMAZON_SET_OPTION_FOUND | ORDER_SET | Same 400pcs/24-value SMD aluminum electrolytic assortment includes 100uF 16V 6.3x5.4mm; footprint class matches production preview
ASSORTMENT | 1 | JTAREA 6390pcs SMD 0603 assortment | covers R1-R10, C3, D1-D4 SS34/1N5822-class; includes SS14 SMA too | mixed 0603 + SMA | RECOMMENDED_AMAZON_BUNDLE | ORDER_OPTION | Amazon.de; 0603 version only, not 0805. Does not solve D5 SOD-123 or C1/C2 bulk SMD electrolytics

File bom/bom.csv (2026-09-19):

qty | category | part | specification | preferred_supplier | verified_status_2026-09-16 | unit_price_eur | url_or_search_note | critical_check
1 | compute | Seeed XIAO ESP32-S3 Sense | 8MB PSRAM/8MB Flash, camera module | Existing/Seeed distributor | Project hardware |  |  | Use Sense camera version
1 | sensor | GY-91 MPU9250+BMP280 | 3.3V I2C | Electronics supplier | Project hardware |  |  | Confirm actual IMU variant
1 | sensor | VL6180X breakout | 7-pin photographed module; VIN 3-5V; I2C | Existing/marketplace | Physical module verified |  |  | Pin order: VIN,2V8,GND,GPIO,SHDN,SCL,SDA
1 | actuator | FH-1502 micro gimbal/servo | 1S-compatible class; PWM | Existing/marketplace | Project hardware |  |  | GPIO42 PWM; Sense PDM microphone unavailable
6 | propulsion | 8520 brushed motor | 8.5x20mm 3.7V, 1.0mm shaft | Amazon.de/LDARC | Variant availability changes |  |  | 1.0mm shaft mandatory
2 | propulsion | 75-76mm propeller set | 2-blade, 1.0mm bore, CW/CCW | RC supplier | Variant availability changes |  |  | Use matched CW/CCW set; verify bore
2 | power | 1S LiHV battery | 3.8V nominal, max 4.35V, BT2.0 preferred | RC supplier | Current V3.4 power profile |  |  | Use LiHV-capable charger
1 | power | 1S to 5V boost module | >=0.7A continuous, >=1A transient recommended | Electronics supplier | Required by V3.4 |  |  | Do not feed raw LiHV directly to XIAO 5V/BAT
4 | electronics | AO3400A | N-MOSFET 30V SOT-23 | Amazon.de | Received / physically available |  | Amazon listing: 50 pcs A09T / AO3400(A), SOT-23, 30V 5.8A | Pin 1 Gate, 2 Source, 3 Drain; verify A09T top marking before placement
4 | electronics | SS34-class Schottky | >=3A, >=40V preferred; SMA/DO-214AC compatible | Electronics supplier | Received / photo-verified SS34 marking |  |  | D1-D4 motor flyback; cathode/band to VBAT; do NOT substitute SS14 1A
1 | electronics | Schottky diode D5 | >=1A, >=40V; e.g. SS14/1N5819W class | Electronics supplier | Required by V3.4 |  |  | Boost 5V isolation; cathode to XIAO 5V; SS14 is acceptable here, not for motor flyback D1-D4
4 | electronics | 100R resistor | 0603/0805 or through-hole | Electronics supplier | Commodity |  |  | Series gate resistor
6 | electronics | 100k resistor | 0603/0805 or through-hole | Electronics supplier | Commodity |  |  | 4 gate pulldowns + 2 battery divider
1 | electronics | 470uF capacitor | 10V low-ESR | BEEYUIHF 925pcs 36-value electrolytic kit | Value available in workshop kit but final part still unverified |  | Kit includes 470uF/10V radial electrolytic; kit label does not establish low-ESR | C1 across VBAT/GND; final PCB part must be low-ESR and footprint-compatible
1 | electronics | 100uF capacitor | >=10V low-ESR | BEEYUIHF 925pcs 36-value electrolytic kit | Value available in workshop kit but final part still unverified |  | Kit includes radial 100uF values at >=16V; kit label does not establish low-ESR | C2 across VBAT/GND; final PCB part must be low-ESR and footprint-compatible
5 | electronics | 100nF ceramic | one ADC filter + one directly across each motor | Electronics supplier | Still required separately |  |  | Not contained in electrolytic capacitor kit; use ceramic MLCC/appropriate motor-terminal capacitor | Motor capacitors directly at terminals
1 | power | BT2.0 pigtail | 20-22AWG preferred | RC supplier | Recommended |  |  | Check polarity
4 | power | JST-XH or equivalent motor connector | 2-pin; suitable current path | Electronics supplier | Recommended |  |  | Do not use Dupont for motor current
1 | mechanical | 70x30mm perfboard | 2.54mm pitch | Electronics supplier | Prototype |  |  | Use V3.4 coordinate convention
1 | mechanical | PETG filament | 1.75mm | Existing stock | Local |  |  | Frame
1 | mechanical | TPU 95A filament | 1.75mm | Optional | Local |  |  | Camera cradle

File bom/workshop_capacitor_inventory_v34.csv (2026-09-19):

value | voltage | dimensions_mm | technology | possible_v34_role | final_pcb_status | notes
470uF | 10V | 6x7 | radial_THT_aluminum | C1 electrical value | not_recommended | Low-ESR not specified; final V3.4 requires low-ESR SMD
100uF | 25V | 6x12 | radial_THT_aluminum | C2 electrical value | not_recommended | Higher voltage is electrically OK; THT and ESR unknown
100uF | 35V | 6x7 | radial_THT_aluminum | C2 electrical value | not_recommended | Compact THT option for bench use only; ESR unknown

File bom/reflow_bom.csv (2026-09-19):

qty | category | item | requirement | status_for_current_build | notes
1 | equipment | YIHUA YH-853AAA | Preheater + low-airflow hot air | existing | 120x120 mm preheater; use moderate low-temp profile
1 | tool | IceDrone V3.4 stencil | Matches 70x30 mm PCB paste apertures | existing | Stencil may be larger than PCB; it is removed before heating
1 | consumable | Sn42Bi58 solder paste | Lead-free eutectic; 138 C melting point; particles 25-45 um | received_verified | BEEYUIHF 30 g; label verified from received syringe on 2026-09-19
1 | consumable | Kapton high-temperature tape | Narrow tape suitable for stencil hinge and thermocouple | existing | Keep tape off pads/apertures
1 | tool | Squeegee or rigid plastic card | Straight undamaged edge | required | 45-60 degree print angle
2-4 | fixture | FR4/old-PCB shims | Same thickness as IceDrone PCB | recommended | Support oversized stencil so it stays planar
1 | cleaning | Isopropyl alcohol | Prefer 99% electronics grade | recommended | PCB pre-clean and stencil clean
1 pack | cleaning | Lint-free wipes | Low-lint electronics wipes | recommended | Do not leave fibers in stencil apertures
1 pair | tool | ESD fine tweezers | Fine tip; straight or curved | required | Place SMD parts without smearing paste
1 | tool | Magnifier or microscope | Enough resolution for SOT-23 and small passives | strongly recommended | Inspect paste print and joints
1 | measurement | K-type thermocouple + meter | Thin bead probe | strongly recommended | Measure actual PCB temperature; station display is not pad temperature
1 | safety | ESD mat/wrist strap | Electronics-safe ESD setup | recommended | Especially before XIAO/sensor handling
1 | safety | Fume extraction | Local extraction or well-ventilated workstation | recommended | Flux vapors should not be inhaled
1 | consumable | No-clean flux | Electronics flux compatible with lead-free rework | existing/ordered | For rework only; do not spread under stencil paste
1 | consumable | Desoldering braid | Fine 1.0-1.5 mm | recommended | Correct bridges/excess solder with flux
1 | tool | Heat-resistant work mat | Flat and stable | recommended | For printing/placement away from preheater
1 pair | safety | Nitrile gloves | Powder-free | optional | Useful when cleaning/handling paste; still wash hands
1 | organization | SMD parts tray | Labeled compartments | recommended | Keep designators/orientations traceable

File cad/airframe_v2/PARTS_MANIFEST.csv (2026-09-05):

file | quantity | material | recommended | orientation | support | notes
frame_v2.stl | 1 | PETG | yes | flat bottom | no | Main 123 mm Quad-X airframe; print motor cup coupon first
battery_sled_650_v2.stl | 1 | PETG or TPU | yes | flat floor | no | Adjustable +/- several mm using 30x30 M2 longitudinal slots
electronics_deck_v2.stl | 1 | PETG | yes | flat | no | Universal 20-30 mm carrier/perfboard tie slots
m2_spacers_5mm_set4.stl | 1 set | PETG | yes | flat | no | Contains 4 separate 5 mm spacers
imu_gy91_saddle.stl | 1 | TPU 95A | yes | flat | no | Measure actual GY-91; parametric dimensions in library
xiao_camera_mount_15deg.stl | 1 | PETG or TPU | yes | base flat | no | Forward camera mount; USB-C up; approximately 15 degree downward camera angle
flight_cage_v2.stl | 1 | PETG | yes | feet on bed | build-plate/tree for top rails | Recommended lightweight airborne protection
canopy_v2.stl | 1 | PETG | no | roof on bed | auto if needed | More protection but heavier than flight cage
prop_guard_corner_v2.stl | 4 | PETG | no | flat | usually no | Indoor/low-energy testing; remove for best thrust-to-weight
motor_cup_test_v2.stl | 1 | PETG | test only | flat | no | Five IDs: 8.55/8.60/8.65/8.70/8.75 mm

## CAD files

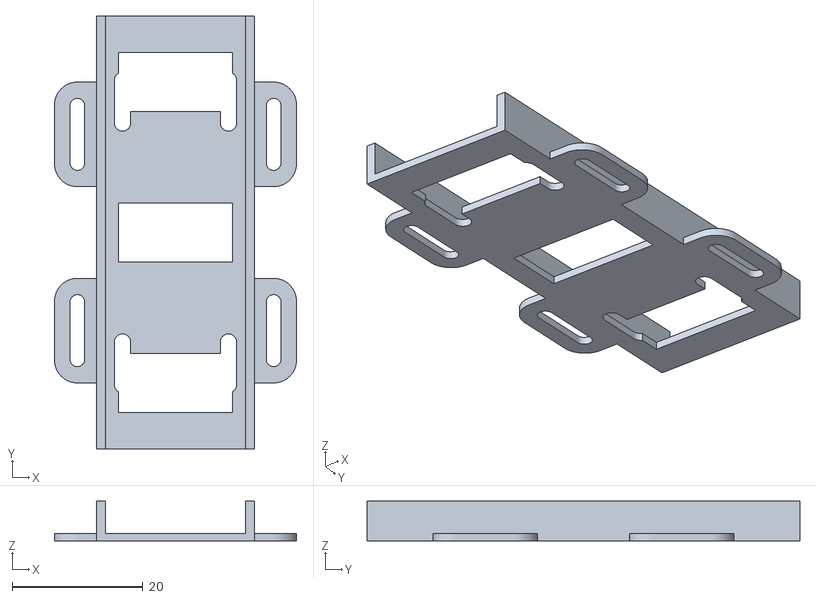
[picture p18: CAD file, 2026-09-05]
cad/airframe_v2/stl/battery_sled_650_v2.stl
37.0 x 66.2 x 6.06

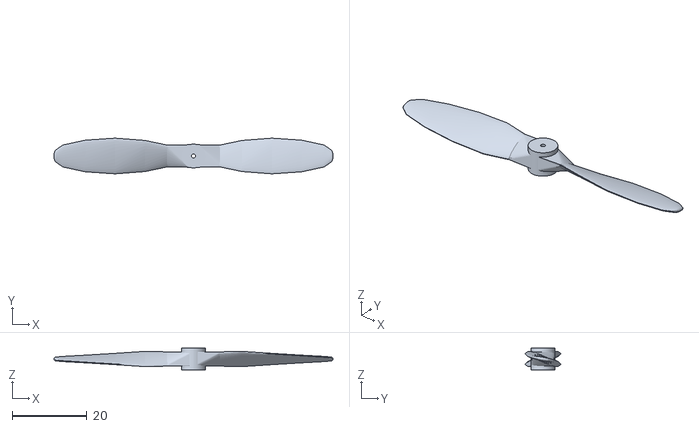
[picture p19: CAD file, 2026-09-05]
cad/propellers/stl/IceDrone_75mm_Standard_CW.stl
74.8 x 9.58 x 5.80

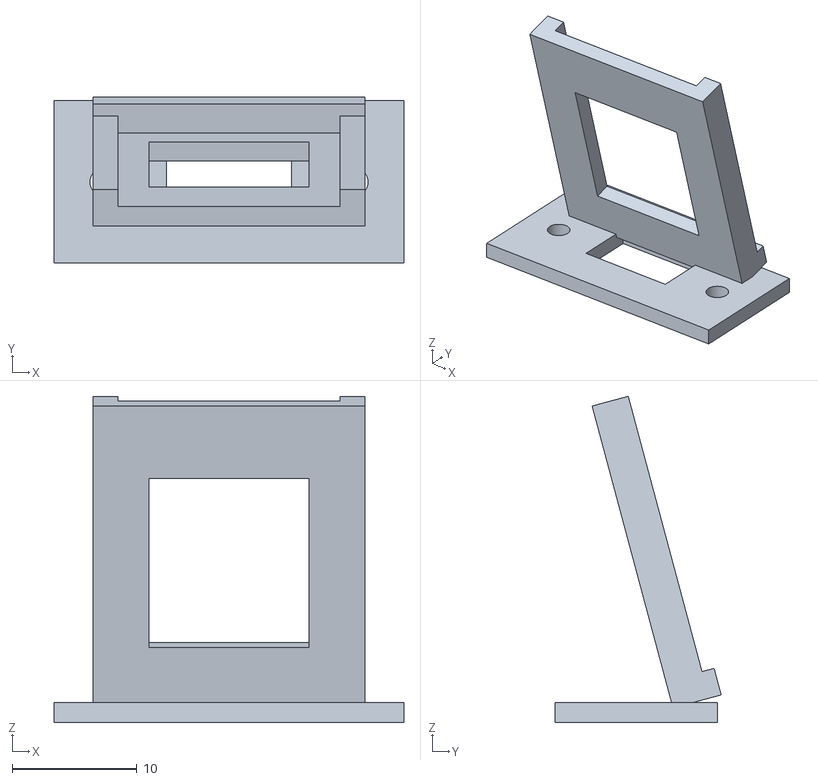
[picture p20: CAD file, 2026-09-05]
cad/airframe_v2/stl/xiao_camera_mount_15deg.stl
28.0 x 13.3 x 26.1

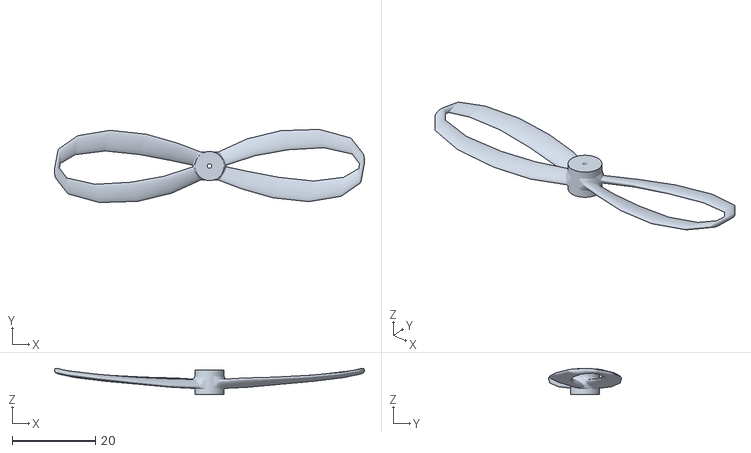
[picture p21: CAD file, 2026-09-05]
cad/propellers/stl/IceDrone_75mm_Toroidal_Quiet_CW.stl
74.6 x 17.6 x 6.37

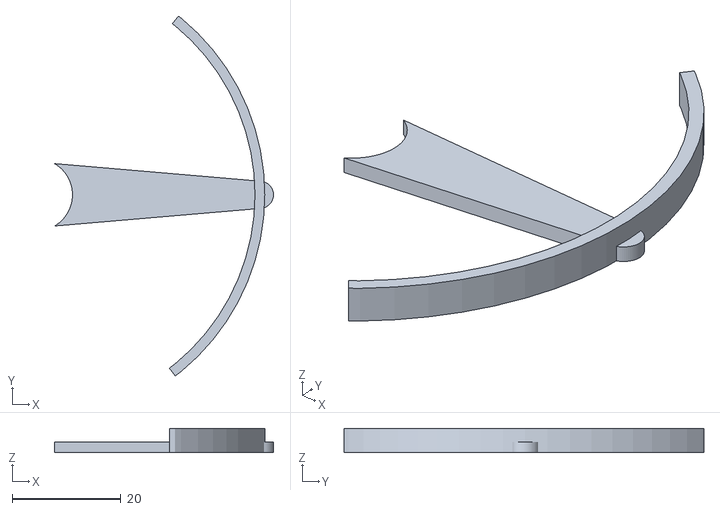
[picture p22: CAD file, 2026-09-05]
cad/airframe_v2/stl/prop_guard_corner_v2.stl
40.2 x 66.1 x 4.50

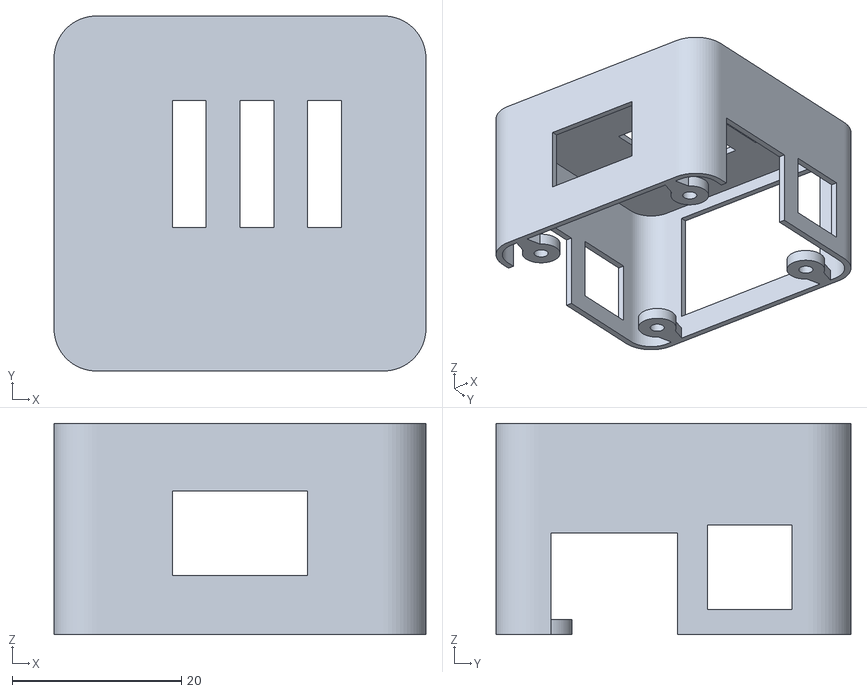
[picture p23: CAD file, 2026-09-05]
cad/airframe_v2/stl/canopy_v2.stl
44.0 x 42.0 x 25.0

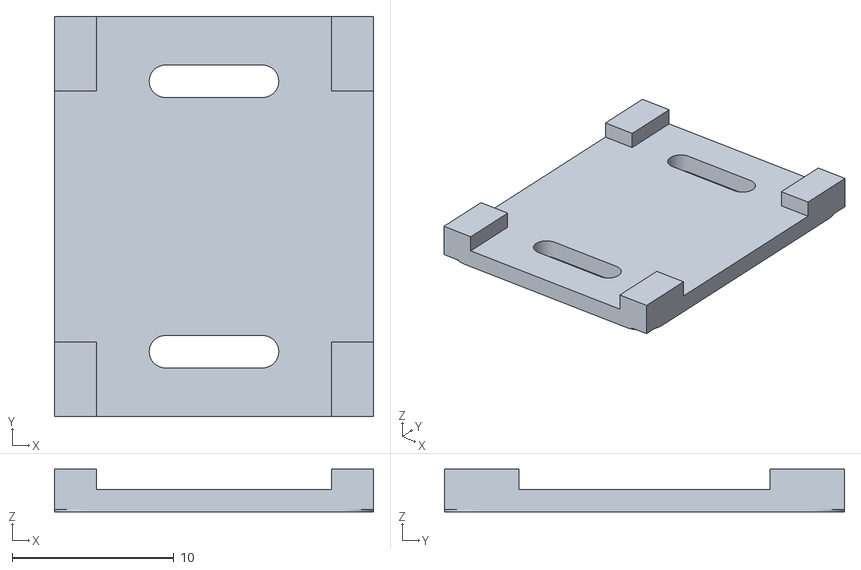
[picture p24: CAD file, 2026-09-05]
cad/airframe_v2/stl/imu_gy91_saddle.stl
19.7 x 24.7 x 2.65

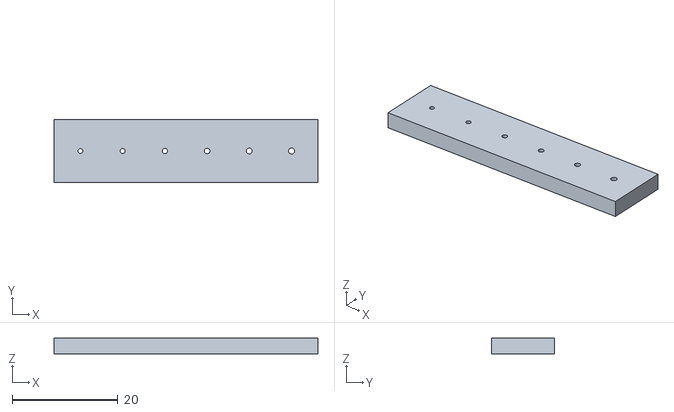
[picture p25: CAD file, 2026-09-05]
cad/propellers/stl/IceDrone_1mm_Shaft_Fit_Coupon.stl
50.0 x 12.0 x 3.00

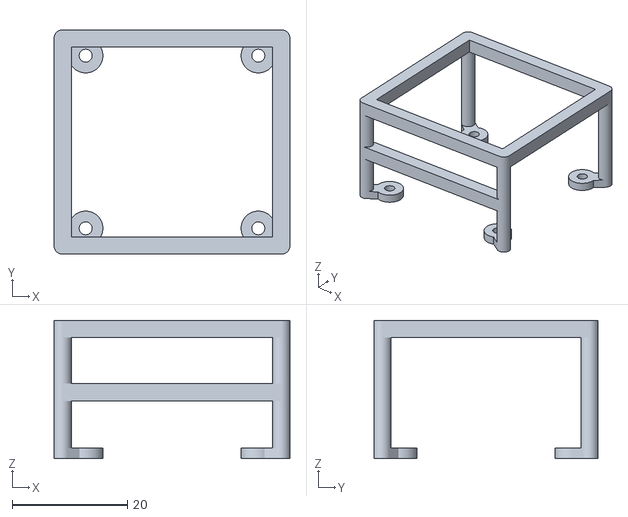
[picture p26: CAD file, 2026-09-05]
cad/airframe_v2/stl/flight_cage_v2.stl
41.0 x 39.0 x 24.0

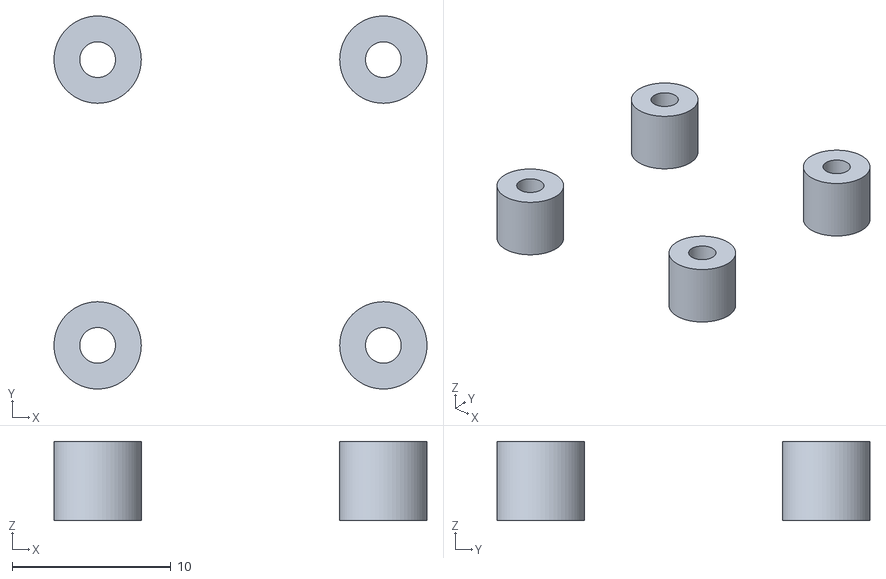
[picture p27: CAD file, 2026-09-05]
cad/airframe_v2/stl/m2_spacers_5mm_set4.stl
23.5 x 23.5 x 5.00

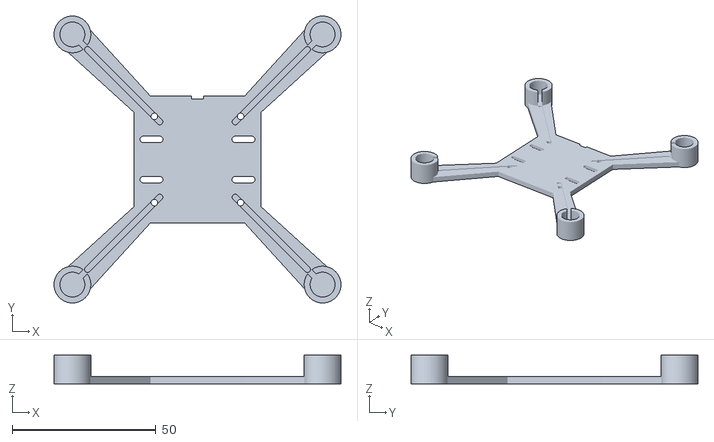
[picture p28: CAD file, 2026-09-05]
cad/airframe_v2/stl/frame_v2.stl
99.8 x 99.8 x 10.0

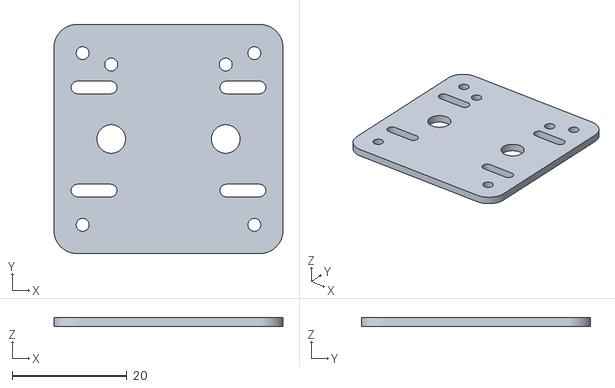
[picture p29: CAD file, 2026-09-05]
cad/airframe_v2/stl/electronics_deck_v2.stl
40.0 x 40.0 x 1.60

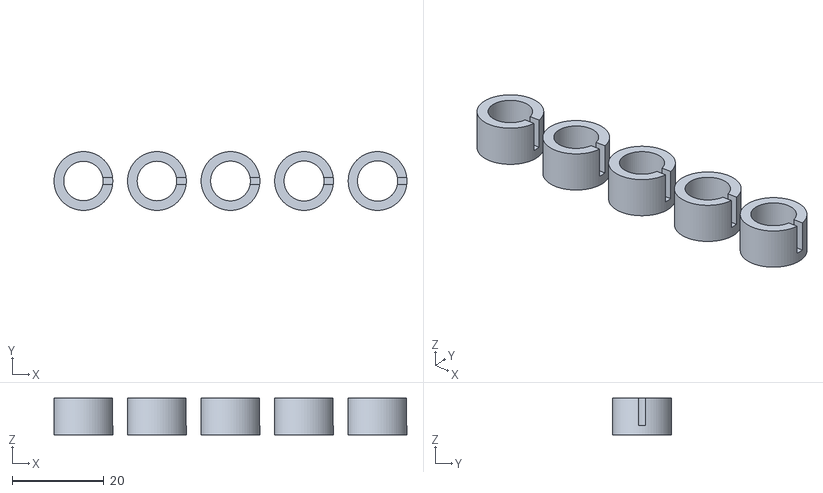
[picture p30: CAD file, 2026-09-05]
cad/airframe_v2/stl/motor_cup_test_v2.stl
76.8 x 12.8 x 8.00

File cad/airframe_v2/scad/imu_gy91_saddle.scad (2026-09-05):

include <icedrone_v2_lib.scad>
imu_gy91_saddle();

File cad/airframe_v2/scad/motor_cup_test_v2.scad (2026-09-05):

include <icedrone_v2_lib.scad>
motor_cup_test_v2();

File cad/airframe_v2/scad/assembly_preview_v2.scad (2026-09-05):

include <icedrone_v2_lib.scad>
assembly_preview_v2(show_canopy=true,show_guards=false);

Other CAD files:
cad/propellers/stl/IceDrone_75mm_Standard_CCW.stl
cad/propellers/stl/IceDrone_75mm_Toroidal_Quiet_CCW.stl
cad/airframe_v2/scad/battery_sled_650_v2.scad
cad/airframe_v2/scad/canopy_v2.scad
cad/airframe_v2/scad/electronics_deck_v2.scad
cad/airframe_v2/scad/flight_cage_v2.scad
cad/airframe_v2/scad/frame_v2.scad
cad/airframe_v2/scad/icedrone_v2_lib.scad
cad/airframe_v2/scad/m2_spacers_5mm_set4.scad
cad/airframe_v2/scad/prop_guard_corner_v2.scad
cad/airframe_v2/scad/xiao_camera_mount_15deg.scad
cad/propellers/scad/icedrone_prop_75mm_standard.scad
cad/propellers/scad/icedrone_prop_75mm_toroidal.scad
cad/propellers/scad/shaft_fit_coupon_1mm.scad

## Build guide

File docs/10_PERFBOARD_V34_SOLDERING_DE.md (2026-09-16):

[← Docs index](README.md)

# 10 - Perfboard V3.4: Lötplan und Inbetriebnahme

> **Gültige Revision:** Diese Anleitung gilt für **IceDrone Perfboard V3.4 HW-VERIFIED**.  
> **V3.2 und V3.3 nicht mehr als Lötvorlage verwenden.** V3.4 korrigiert insbesondere M2 auf GPIO44/D7, die VL6180X-Belegung, die XIAO-Stromversorgung und die Motor-Freilaufdioden.

IceDrone Perfboard V3.4 — Lötseite

Maschinenlesbare Referenzen:

- [`hardware/perfboard_v34_netlist.csv`](../hardware/perfboard_v34_netlist.csv)
- [`hardware/perfboard_v34_pin_matrix.csv`](../hardware/perfboard_v34_pin_matrix.csv)
- [`hardware/pinmap.csv`](../hardware/pinmap.csv)
- [`hardware/motor_stage_netlist.csv`](../hardware/motor_stage_netlist.csv)

## 1. Koordinatensystem

Die Koordinaten werden **niemals** beim Umdrehen der Platine neu nummeriert.

| Ansicht | links → rechts | oben → unten |
|---|---|---|
| Bauteilseite | A B C D E F G H I J | 1 … 24 |
| Lötseite | J I H G F E D C B A | 1 … 24 |

Fest definiert:

- `A1-A24` = VBAT
- `J1-J24` = GND
- `E12` = **unbenutzt**
- XIAO ESP32-S3 Sense sitzt **nicht** auf der Lochrasterplatine, sondern wird über die vorgesehenen Anschlusspads verbunden.

Markiere vor dem ersten Lötpunkt auf beiden Seiten der realen Platine mindestens `A1`, `J1`, `A24` und `J24` mit einem feinen Permanentmarker.

## 2. Lötstation und Material

Für das vorhandene Sn60PbCu2-Röhrenlot sind folgende Startwerte für die YIHUA YH-853AAA praxisgerecht:

| Arbeit | Startwert |
|---|---|
| normale Lochraster-Lötstelle | 320–330 °C Lötkolben |
| große VBAT/GND-Drahtschiene | 335–350 °C Lötkolben |
| 0603/SOT-23 mit Heißluft | 290–305 °C |
| Heißluftstrom | niedrig, etwa 20–30 % |

Heißluft ist für die **SMD-Bauteile**, nicht zum Aufbau der Stromschienen gedacht. Für VBAT/GND 0,6–0,8-mm-verzinnten Kupferdraht verwenden. Die Motorstrompfade ebenfalls als Draht bzw. sehr kurze, kräftige Verbindungen ausführen und nicht als lange reine Lötzinnbrücken.

Bei altem Röhrenlot zusätzlich Elektronik-Flussmittel verwenden, wenn das Lot schlecht benetzt. Kunststoff-Steckverbinder erst nach den Heißluftarbeiten einbauen.

### AO3400A

AO3400A ist SOT-23. Laut Hersteller-Pinout gilt:

- Pin 1 = Gate
- Pin 2 = Source
- Pin 3 = Drain

Auf 2,54-mm-Lochraster deshalb **SOT-23-Adapter** oder sehr kurze Dead-Bug-Leitungen verwenden. Die Koordinaten im Plan beschreiben die elektrischen Knoten, nicht die mechanische Lage eines direkt eingesteckten SOT-23.

## 3. Prüfprinzip

Nach **jedem** Bauabschnitt:

1. gewünschten Pfad auf Durchgang prüfen;
2. unmittelbar benachbarte Netze auf Kurzschluss prüfen;
3. VBAT gegen GND prüfen;
4. erst danach mit dem nächsten Abschnitt fortfahren.

Bei eingebauten Elkos kann die Widerstandsanzeige beim Messen VBAT↔GND kurz niedrig beginnen und dann ansteigen, weil sich die Kondensatoren über das Multimeter laden. Ein **dauerhafter** Wert nahe 0 Ω ist dagegen ein Fehler.

Keine Propeller während Aufbau oder elektrischer Inbetriebnahme montieren.

---

# 4. Schritt-für-Schritt-Lötplan

## Schritt 1 — Hauptschienen

Auf der **Lötseite**:

- `A1 → A24`: durchgehende VBAT-Schiene, 0,6–0,8 mm verzinnter Kupferdraht.
- `J1 → J24`: durchgehende GND-Schiene, 0,6–0,8 mm verzinnter Kupferdraht.
- `E12` frei lassen.

**Multimeter:**

- `A1 ↔ A24`: Durchgang.
- `J1 ↔ J24`: Durchgang.
- `A1 ↔ J1`: **kein** Durchgang.
- `E12`: weder VBAT noch GND.

Erst nach diesem Test weiterarbeiten.

## Schritt 2 — Motor 1 komplett aufbauen

M1 = hinten links, XIAO D3 / GPIO4.

Bare-Wire-Verbindungen:

- `A2 → B2`: Motor+ / VBAT.
- `C2 → D2`: Motor− / Drain.
- `E2 → J2`: Q1 Source → GND.
- `F4 → J4`: R5-Unterseite → GND.

Bauteile:

- Motor+ Anschluss = `B2`.
- Motor− Anschluss = `C2`.
- D1 = SS34-Klasse ≥3 A: **Anode `C2`, Kathode/Band `B2`**.
- Q1 Drain = `D2`.
- Q1 Source = `E2`.
- Q1 Gate = `E3`.
- R1 100 Ω = `E3 → F3`.
- R5 100 kΩ = `E3 → F4`.
- isolierte PWM-Leitung = `F3 → B9`.

**Prüfung vor Anschluss eines Motors:**

- `E2 ↔ J2`: nahezu 0 Ω.
- `E3 ↔ GND`: ungefähr 100 kΩ.
- `F3 ↔ E3`: ungefähr 100 Ω.
- Diodentest `C2` (rot/+) → `B2` (schwarz/−): typische Schottky-Flussspannung; umgekehrt OL/kein Durchgang.
- `D2 ↔ GND`: kein harter Kurzschluss.
- `B2 ↔ GND`: kein harter Kurzschluss.

Wenn M1 fehlerfrei ist, erst dann die anderen drei Kanäle kopieren.

## Schritt 3 — Motor 2

M2 = hinten rechts, **XIAO D7 / GPIO44**. GPIO3 wird in V3.4 nicht verwendet.

- `A6 → B6`: VBAT.
- `C6 → D6`: Motor− / Drain.
- `E6 → J6`: Q2 Source → GND.
- Q2 Gate = `E7`.
- D2: Anode `C6`, Kathode/Band `B6`.
- R2 100 Ω = `E7 → F7`.
- R6 100 kΩ = `E7 → F8`.
- `F8 → J8`: Pulldown-GND.
- PWM = isoliert `F7 → C9`.

Prüfungen analog zu M1.

## Schritt 4 — Motor 3

M3 = vorne rechts, XIAO D5 / GPIO6.

- `A14 → B14`
- `C14 → D14`
- `E14 → J14`
- Q3 Gate = `E15`
- D3: Anode `C14`, Kathode/Band `B14`
- R3 100 Ω = `E15 → F15`
- R7 100 kΩ = `E15 → F16`
- `F16 → J16`
- PWM = isoliert `F15 → D9`

Prüfungen analog zu M1.

## Schritt 5 — Motor 4

M4 = vorne links, XIAO D4 / GPIO5.

- `A19 → B19`
- `C19 → D19`
- `E19 → J19`
- Q4 Gate = `E20`
- D4: Anode `C19`, Kathode/Band `B19`
- R4 100 Ω = `E20 → F20`
- R8 100 kΩ = `E20 → F21`
- `F21 → J21`
- PWM = isoliert `F20 → E9`

Prüfungen analog zu M1.

### Motorentstörung

Je Motor 100 nF Keramik **direkt an den beiden Motoranschlüssen** vorsehen. Die Motorleitungen nach Möglichkeit paarweise verdrillen.

## Schritt 6 — C1 und C2

- `A10 → B10`: C1 Plus-Zuführung.
- `C10 → J10`: C1 Minus → GND.
- C1 = **470 µF / 10 V low-ESR**, `+` an `B10`, `−` an `C10`.
- `A11 → B11`: C2 Plus-Zuführung.
- `C11 → J11`: C2 Minus → GND.
- C2 = **100 µF / 10 V low-ESR**, `+` an `B11`, `−` an `C11`.

Vor dem Einlöten die Polaritätsmarkierung des konkreten Elkos kontrollieren.

## Schritt 7 — Akku, Boost und XIAO-Versorgung

Akku:

- `A12` = Akku+ / VBAT.
- `J12` = Akku− / GND.

Boost-Modul:

- `A13` = Boost VIN+.
- `J13` = Boost GND.
- geregelter Boost-Ausgang 5 V = `G12`.
- D5 Schottky: **Anode `G12`, Kathode/Band `H12`**.
- `H12` = XIAO 5V.
- `I13 → J13`: XIAO GND.
- `G13` = XIAO 3V3 **Ausgang** für die Sensoren.

**Wichtig:** Rohes 1S-LiHV/VBAT darf in V3.4 **nicht** direkt an XIAO 5V oder BAT gelegt werden.

**Prüfung ohne XIAO:**

- `A12 ↔ A1`: Durchgang.
- `J12 ↔ J1`: Durchgang.
- `A12 ↔ H12`: kein direkter Durchgang.
- Diodentest D5: `G12 → H12` leitend, Gegenrichtung sperrend.
- Boost vor Anschluss des XIAO separat prüfen: Ausgang ungefähr 5 V.

## Schritt 8 — Batterie-ADC

- `A17 → B17`: VBAT zum oberen Teilerwiderstand.
- R9 100 kΩ = `B17 → C17`.
- R10 100 kΩ = `C17 → D17`.
- C3 100 nF = `C17 → D17` parallel zu R10.
- `D17 → J17`: GND.
- ADC-Signal isoliert = `C17 → F9`.
- `F9` später an XIAO D0 / GPIO1.

Ohne XIAO und ohne Akku:

- `B17 ↔ C17`: ca. 100 kΩ.
- `C17 ↔ D17`: ca. 100 kΩ; C3 kann die Messung kurz beeinflussen.
- DC-Verhältnis nach Inbetriebnahme: `V_ADC ≈ VBAT / 2`.

## Schritt 9 — XIAO-Signalanschlüsse

Anschlussfeld Reihe 9:

| Perfboard | Funktion | XIAO |
|---|---|---|
| B9 | M1 PWM | D3 / GPIO4 |
| C9 | M2 PWM | **D7 / GPIO44** |
| D9 | M3 PWM | D5 / GPIO6 |
| E9 | M4 PWM | D4 / GPIO5 |
| F9 | VBAT ADC | D0 / GPIO1 |
| G9 | SDA | D1 / GPIO2 |
| H9 | SCL | D6 / GPIO43 |
| I9 | Gimbal PWM | GPIO42 Testpad |

I²C in der Firmware zwingend explizit initialisieren:

```cpp
Wire.begin(2, 43);
```

GPIO42 kollidiert beim XIAO Sense mit dem PDM-Mikrofon-Clock; das Mikrofon ist in diesem Hardwareprofil daher nicht verfügbar.

## Schritt 10 — GY-91

- `G13 → G23`: 3V3, isoliert.
- `G9 → H23`: SDA, isoliert.
- `H9 → I23`: SCL, isoliert.
- `J23`: GND.

Header:

- `G23` = 3V3
- `H23` = SDA
- `I23` = SCL
- `J23` = GND

## Schritt 11 — VL6180X

Das tatsächlich fotografierte Breakout hat bei Frontansicht, Schrift oben und Stiftleiste unten:

`VIN | 2V8 | GND | GPIO | SHDN | SCL | SDA`

V3.4 nutzt:

- `F24` = VL VIN → XIAO 3V3 (`G13 → F24`, isoliert)
- `G24` = SHDN optional / normalerweise NC
- `H24` = SDA (`G9 → H24`)
- `I24` = SCL (`H9 → I24`)
- `J24` = GND

Am Modul:

- 2V8 = **NC**
- GPIO = **NC**

Die 2V8-Leitung des Breakouts ist ein Reglerausgang und wird nicht mit 3V3 verbunden.

## Schritt 12 — FH-1502 Gimbal

- `A18 → H18`: VBAT.
- `H18` = FH+.
- `I18` = FH PWM.
- `J18` = FH GND.
- PWM isoliert `I9 → I18`.

## Schritt 13 — Abschlussprüfung ohne XIAO, Motoren und Akku

Prüfliste:

- [ ] A1–A24 durchgängig.
- [ ] J1–J24 durchgängig.
- [ ] kein stabiler Kurzschluss VBAT↔GND.
- [ ] E12 frei.
- [ ] Q1…Q4 Source jeweils auf GND.
- [ ] Q1…Q4 Drain jeweils nur am zugehörigen Motor−/Flyback-Netz.
- [ ] Gate-Pulldowns jeweils ca. 100 kΩ nach GND.
- [ ] D1…D4 Band/Kathode jeweils Richtung VBAT/Motor+.
- [ ] D5 Band/Kathode Richtung XIAO 5V (`H12`).
- [ ] C1/C2 Polarität korrekt.
- [ ] M2-PWM geht nach `C9` / GPIO44, **nicht GPIO3**.
- [ ] SDA und SCL nicht vertauscht.
- [ ] VL6180X 2V8 und GPIO bleiben NC.
- [ ] kein direkter VBAT-Pfad zu XIAO 5V.

## Schritt 14 — Erstes Einschalten

1. **Keine Propeller.**
2. XIAO, GY-91, VL6180X, Gimbal und Motoren zunächst abstecken.
3. Wenn verfügbar: Labornetzteil auf etwa 3,7 V und zunächst 100 mA Stromlimit.
4. Rohes VBAT/GND einspeisen. Bei sofortigem Stromlimit: ausschalten und Fehler suchen.
5. Boost-Modul anschließen und dessen Ausgang messen, bevor der XIAO verbunden wird.
6. XIAO zunächst separat per USB testen.
7. Danach XIAO mit der geprüften 5-V-Versorgung verbinden.
8. Sensoren einzeln hinzufügen.
9. Motoren zuletzt, weiterhin ohne Propeller.
10. Mit `firmware/bench_test/` jeden Motor einzeln mit kleiner PWM pulsen.

Bei unerwartetem Motorlauf sofort die Versorgung trennen und zuerst MOSFET-Pinout, Gate-Pulldown und Gate/Drain-Brücken prüfen.

## 5. Empfohlene SMD-Lernreihenfolge

Für die Lochraster-Testplatine:

1. 100-Ω- und 100-kΩ-Widerstände;
2. D5 bzw. eine Schottky-Diode;
3. SS34-Dioden;
4. AO3400A auf SOT-23-Adapter;
5. C3 100 nF;
6. erst danach die größeren Elkos und Steckverbinder.

Bei Heißluft zunächst ein Stück Rest-Lochraster mit einem Ersatzwiderstand oder Ersatz-MOSFET üben. Pads vorverzinnen, Flussmittel verwenden, Teil mit Pinzette positionieren und mit möglichst niedrigem Luftstrom erwärmen.

---

[← 09 - Amazon.de Order List](09_AMAZON_ORDER_LIST_DE.md) | [Docs index](README.md)

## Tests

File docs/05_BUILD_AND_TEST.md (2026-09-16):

[← Docs index](README.md)

# 05 - Build and Test

Step-by-step assembly and bring-up for IceDrone V3.4. Follow the stages in order; each stage gates the next.

For the 70×30 mm perfboard prototype, use the detailed hole-by-hole guide:

**[10 - Perfboard V3.4 soldering and bring-up](10_PERFBOARD_V34_SOLDERING_DE.md)**

```mermaid
flowchart TD
    A["Stage A: print & mechanical fit"] --> B["Stage B: V3.4 motor electronics"]
    B --> C["Stage C: polarity & current-limited power-up"]
    C --> D["Stage D: XIAO/camera smoke test"]
    D --> E["Stage E: IMU orientation"]
    E --> F["Stage F: motor mapping (no props)"]
    F --> G["Stage G: motor rotation"]
    G --> H["Stage H: battery ADC calibration"]
    H --> I["Stage I: video stress test"]
    I --> J["Stage J: pre-prop checklist"]
    J --> K(("Fit propellers"))
```

## Tools and consumables

- soldering iron + fine/chisel tip
- thin electronics solder + flux
- hot air optional for SMD work
- multimeter with continuity, resistance, diode and DC-voltage modes
- bench power supply with adjustable current limit strongly recommended
- SOT-23 adapter boards or material for very short dead-bug wiring
- 0.6–0.8 mm tinned copper wire for VBAT/GND rails
- 28–30 AWG insulated wire for signals
- 22–24 AWG or otherwise suitably rated wire for battery/motor current
- isopropyl alcohol + brush/lint-free wipes
- heat-shrink tubing
- USB-C data cable
- permanent marker / wire labels

## Stage A - print and mechanical fit

1. Print the current Airframe V2 parts from `cad/airframe_v2/`.
2. Test-fit all four 8520 motors before wiring.
3. Verify each motor shaft is 1.0 mm.
4. Test-fit one propeller for bore fit, then remove it again.
5. Fit XIAO/camera and battery holders but keep the electronics accessible.
6. Do not fit propellers again until Stage J is complete.

## Stage B - build V3.4 motor electronics

Use [`hardware/motor_stage_netlist.csv`](../hardware/motor_stage_netlist.csv), [`hardware/pinmap.csv`](../hardware/pinmap.csv) and, for perfboard, [`hardware/perfboard_v34_netlist.csv`](../hardware/perfboard_v34_netlist.csv).

| Channel | MOSFET | Gate resistor | Gate pulldown | Flyback diode | Position | GPIO |
|---|---|---|---|---|---|---|
| 1 | Q1 | R1 | R5 | D1 | rear-left | GPIO4 / D3 |
| 2 | Q2 | R2 | R6 | D2 | rear-right | **GPIO44 / D7** |
| 3 | Q3 | R3 | R7 | D3 | front-right | GPIO6 / D5 |
| 4 | Q4 | R4 | R8 | D4 | front-left | GPIO5 / D4 |

For each channel:

1. install the 100 kΩ gate pulldown;
2. install the 100 Ω gate resistor;
3. install the AO3400A with verified Gate/Source/Drain orientation;
4. install an **SS34-class ≥3 A Schottky** flyback diode:
   - anode = motor− / MOSFET drain
   - cathode/band = VBAT / motor+
5. verify source-to-GND continuity;
6. verify gate-to-GND is approximately 100 kΩ;
7. verify the flyback diode in diode mode;
8. verify there is no drain-to-GND hard short.

After all four channels pass:

- C1 = **470 µF / 10 V low-ESR** across VBAT/GND
- C2 = **100 µF / 10 V low-ESR** across VBAT/GND
- R9/R10 = 100k/100k battery divider
- C3 = 100 nF from ADC midpoint to GND
- one 100 nF ceramic directly across each motor's terminals

### V3.4 pin changes that must not be back-ported incorrectly

- M2 is **GPIO44 / D7**, not GPIO3.
- GPIO3 is intentionally unused.
- I2C is SDA=GPIO2/D1 and SCL=GPIO43/D6.
- firmware must call `Wire.begin(2, 43)`.
- D1-D4 are SS34-class, not SS14.
- raw LiHV does not feed XIAO BAT/5V directly.

## Stage C - power architecture and current-limited first power

V3.4 power path:

`1S LiHV VBAT → motors + gimbal`

and separately:

`VBAT → off-board 1S→5V boost → D5 Schottky → XIAO 5V`

With XIAO, sensors, gimbal and motors initially disconnected:

1. measure VBAT-to-GND: no hard short;
2. verify battery polarity;
3. verify D5 orientation;
4. verify there is no direct VBAT→XIAO_5V continuity;
5. if available, apply about 3.7 V from a bench supply with a low initial current limit (for example 100 mA);
6. if the supply immediately current-limits, disconnect and troubleshoot;
7. connect the boost module and measure its regulated output before connecting the XIAO;
8. only then connect the XIAO 5V/GND path.

Keep the airframe restrained and propellers removed.

## Stage D - XIAO/camera smoke test

1. With battery power disconnected, connect XIAO over USB.
2. Flash `firmware/bench_test/main.cpp`.
3. Open the serial monitor at 115200 baud.
4. Confirm the startup banner appears.
5. Confirm the camera initializes.
6. Capture repeated JPEG frames and verify there are no resets.
7. Only after USB testing passes, test the previously verified boosted 5-V supply.

The bench-test firmware uses the V3.4 motor map `{GPIO4, GPIO44, GPIO6, GPIO5}`.

## Stage E - IMU and I2C

The GY-91 must be mounted rigidly.

V3.4 I2C:

- SDA = GPIO2 / D1
- SCL = GPIO43 / D6

The firmware must explicitly call:

```cpp
Wire.begin(2, 43);
```

Check:

1. stationary gyro settles close to zero after calibration;
2. acceleration magnitude is near 1 g while stationary;
3. roll and pitch signs match the expected frame orientation.

Do not correct wrong IMU axis signs by swapping random motor channels.

## Stage F - motor mapping, no props

Propellers remain removed.

The bench-test command mapping is:

| command | motor | GPIO |
|---:|---|---|
| 0 | rear-left | GPIO4 |
| 1 | rear-right | **GPIO44** |
| 2 | front-right | GPIO6 |
| 3 | front-left | GPIO5 |

Pulse one motor at a time at low duty. If a different physical motor spins, correct the wiring/mapping before continuing.

If a motor runs as soon as power is applied, disconnect power immediately and inspect:

- AO3400A Gate/Source/Drain orientation
- gate-to-drain solder bridges
- missing/bad 100 kΩ gate pulldown
- wrong signal connection

## Stage G - motor rotation

1. identify each motor's rotation with very short low-duty pulses;
2. compare against the Quad-X pattern required by the flight firmware;
3. reverse a brushed motor by swapping its two motor leads;
4. repeat the channel test after every swap.

Do not use wire colour alone to infer direction.

## Stage H - battery ADC calibration

Nominal divider:

`V_ADC = VBAT / 2`

1. measure actual VBAT with a multimeter;
2. read the ADC-derived battery voltage;
3. repeat at two clearly different battery voltages;
4. calculate scale/offset calibration;
5. store the correction in firmware.

C3 = 100 nF at the divider midpoint is intended to reduce motor-noise contamination.

## Stage I - video stress test

Still without propellers:

1. power from the normal battery/boost architecture;
2. start telemetry/video;
3. let the system run for at least 10 minutes;
4. watch for resets, Wi-Fi loss, camera failures and excessive XIAO temperature;
5. gently move the frame and verify the IMU continues to respond.

## Stage J - pre-prop checklist

- [ ] V3.4 wiring used; no V3.2/V3.3 solder map mixed in
- [ ] no VBAT/GND hard short
- [ ] battery polarity verified
- [ ] no raw LiHV connected directly to XIAO 5V/BAT
- [ ] boost output verified before XIAO connection
- [ ] D1-D4 are SS34-class and bands face VBAT
- [ ] C1 = 470 µF / 10 V, C2 = 100 µF / 10 V, polarity correct
- [ ] M2 uses GPIO44/D7, not GPIO3
- [ ] I2C uses GPIO2/GPIO43 and `Wire.begin(2,43)`
- [ ] all four motor channels map to the correct physical motors
- [ ] motor directions match the selected mixer
- [ ] camera passes the stress test
- [ ] IMU orientation verified
- [ ] battery ADC calibrated
- [ ] failsafe/arming behaviour bench-tested
- [ ] antenna and wiring cannot enter the propeller discs
- [ ] no propeller is fitted until every item above passes

Only then continue to [06 - First Flight](06_FIRST_FLIGHT.md).

---
[← 04 - Firmware](04_FIRMWARE.md) | [Docs index](README.md) | Next: [06 - First Flight →](06_FIRST_FLIGHT.md)

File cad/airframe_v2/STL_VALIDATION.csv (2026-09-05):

file | watertight | components | x_mm | y_mm | z_mm | volume_cm3 | PETG_est_g | TPU95A_est_g | faces
battery_sled_650_v2.stl | True | 1 | 37.0 | 66.2 | 6.06 | 2.442 | 3.1 | 2.96 | 2472
canopy_v2.stl | True | 1 | 44.0 | 42.0 | 25.0 | 4.483 | 5.69 | 5.42 | 2632
electronics_deck_v2.stl | True | 1 | 40.0 | 40.0 | 1.6 | 2.331 | 2.96 | 2.82 | 3420
flight_cage_v2.stl | True | 1 | 41.0 | 39.0 | 24.0 | 2.437 | 3.1 | 2.95 | 3244
frame_v2.stl | True | 1 | 99.78 | 99.78 | 10.0 | 10.584 | 13.44 | 12.81 | 5292
imu_gy91_saddle.stl | True | 1 | 19.7 | 24.7 | 2.65 | 0.698 | 0.89 | 0.84 | 892
m2_spacers_5mm_set4.stl | True | 4 | 23.5 | 23.5 | 5.0 | 0.395 | 0.5 | 0.48 | 2048
motor_cup_test_v2.stl | True | 5 | 76.8 | 12.8 | 8.0 | 2.692 | 3.42 | 3.26 | 2640
prop_guard_corner_v2.stl | True | 1 | 40.25 | 66.13 | 4.5 | 1.174 | 1.49 | 1.42 | 372
xiao_camera_mount_15deg.stl | True | 1 | 28.0 | 13.32 | 26.11 | 1.297 | 1.65 | 1.57 | 624

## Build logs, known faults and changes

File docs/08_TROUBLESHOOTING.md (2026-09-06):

[← Docs index](README.md)

# 08 - Troubleshooting

## XIAO resets when motors start

Likely causes:

1. battery voltage sag;
2. insufficient bulk capacitance;
3. long/thin battery wiring;
4. motor noise coupling into the XIAO supply;
5. weak/aged LiPo.

Actions: inspect VBAT with an oscilloscope if available, add/relocate bulk capacitor, shorten wiring, test with a known-good high-C battery, and reduce motor duty during diagnosis.

## Camera works on USB but fails on battery

Measure battery rail during capture. The camera/Wi-Fi load produces substantial transient current. Check antenna, PSRAM settings and power integrity. Current Seeed documentation lists roughly 110 mA typical Wi-Fi-active consumption for the Sense expansion and much higher short peaks in camera operation.

## One motor starts at boot

Immediately disconnect power. Check AO3400 pin orientation, solder bridges and missing gate pulldown. Never troubleshoot this with a prop fitted.

## Craft flips instantly

Do not tune PID. Check, in order:

1. motor numbering;
2. prop location CW/CCW;
3. motor rotation direction;
4. IMU axis orientation;
5. mixer configuration.

## Strong vibration / jello

- replace bent/damaged prop;
- check motor shaft runout;
- make sure the motor is tightly retained;
- use TPU camera cradle;
- verify frame arms are not cracked;
- try another motor if one has worn bearings/bushings.

## Wi-Fi control becomes poor when streaming

- lock video to QVGA;
- one viewer only;
- lower camera frame rate/JPEG quality;
- keep control/telemetry UDP traffic prioritized;
- use the supplied U.FL antenna with clear orientation;
- for a later V2, consider independent RC/SBUS so flight control is not dependent on the video WLAN link.

## Camera initializes but every captured frame is NULL

`esp_camera_init()` returns `ESP_OK` (the sensor answers on SCCB/I2C), but `esp_camera_fb_get()` reliably returns `NULL` afterward.

Observed on a real XIAO Sense unit at the default 20 MHz XCLK. Two independent fixes, both worth trying:

1. Lower `xclk_freq_hz` to 10 MHz and discard one warm-up frame right after init (see `firmware/bench_test/camera.cpp` and `firmware/camera_wifi_test/main.cpp`) — this alone made capture reliable on the affected unit.
2. If frames are still intermittently `NULL` after the XCLK fix, suspect a marginal FPC ribbon-cable seat on the Sense camera module rather than a firmware issue. Re-seating or replacing the camera module resolved a case where roughly 1 in 10–20 frames still failed even at 10 MHz.

`CAMERA_GRAB_WHEN_EMPTY` instead of `CAMERA_GRAB_LATEST` also avoids returning a buffer that a slow consumer is still holding, but did not by itself fix the NULL-frame issue described here.

## ESP32 build breaks after library/core update

Return to the last recorded tested toolchain. Flight firmware should be treated like embedded production software: pin the framework and library versions and re-run the full validation plan after any update.

---
[← 07 - Safety and Legal](07_SAFETY_AND_LEGAL_DE.md) | [Docs index](README.md) | Next: [09 - Amazon.de Order List →](09_AMAZON_ORDER_LIST_DE.md)

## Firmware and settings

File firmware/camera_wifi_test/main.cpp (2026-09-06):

/*
 * IceDrone camera Wi-Fi smoke test - DIAGNOSTIC TOOL ONLY, not the V1 flight firmware.
 * Purpose: view the XIAO Sense camera live over the LAN before Open32Drone integration.
 * No motors, no IMU, no flight-control code. Safe to run on USB power alone.
 */
#include <Arduino.h>
#include <WiFi.h>
#include <esp_http_server.h>
#include "esp_camera.h"
#include "secrets.h"

// XIAO ESP32-S3 Sense OV3660/OV2640 camera pin mapping (see docs/04_FIRMWARE.md)
#define PWDN_GPIO_NUM     -1
#define RESET_GPIO_NUM    -1
#define XCLK_GPIO_NUM     10
#define SIOD_GPIO_NUM     40
#define SIOC_GPIO_NUM     39
#define Y9_GPIO_NUM       48
#define Y8_GPIO_NUM       11
#define Y7_GPIO_NUM       12
#define Y6_GPIO_NUM       14
#define Y5_GPIO_NUM       16
#define Y4_GPIO_NUM       18
#define Y3_GPIO_NUM       17
#define Y2_GPIO_NUM       15
#define VSYNC_GPIO_NUM    38
#define HREF_GPIO_NUM     47
#define PCLK_GPIO_NUM     13

httpd_handle_t stream_httpd = NULL;

bool cameraInit() {
  camera_config_t c{};
  c.ledc_channel = LEDC_CHANNEL_0;
  c.ledc_timer = LEDC_TIMER_0;
  c.pin_d0=Y2_GPIO_NUM; c.pin_d1=Y3_GPIO_NUM; c.pin_d2=Y4_GPIO_NUM; c.pin_d3=Y5_GPIO_NUM;
  c.pin_d4=Y6_GPIO_NUM; c.pin_d5=Y7_GPIO_NUM; c.pin_d6=Y8_GPIO_NUM; c.pin_d7=Y9_GPIO_NUM;
  c.pin_xclk=XCLK_GPIO_NUM; c.pin_pclk=PCLK_GPIO_NUM; c.pin_vsync=VSYNC_GPIO_NUM; c.pin_href=HREF_GPIO_NUM;
  c.pin_sccb_sda=SIOD_GPIO_NUM; c.pin_sccb_scl=SIOC_GPIO_NUM; c.pin_pwdn=PWDN_GPIO_NUM; c.pin_reset=RESET_GPIO_NUM;
  c.xclk_freq_hz=10000000; // Kept at 10 MHz as safety margin: original camera module had a marginal FPC ribbon seat causing fb_get() to return NULL at 20 MHz; replacing the module fixed it, but 10 MHz gives more timing headroom against connector wear.
  c.pixel_format=PIXFORMAT_JPEG;
  c.frame_size=FRAMESIZE_QVGA;
  c.jpeg_quality=18;
  c.fb_count=2;
  c.fb_location=CAMERA_FB_IN_PSRAM;
  c.grab_mode=CAMERA_GRAB_WHEN_EMPTY;
  if (esp_camera_init(&c) != ESP_OK) return false;

  // Discard the first frame: on this sensor the pipeline needs one full
  // frame cycle after init before fb_get() reliably returns real data.
  delay(300);
  camera_fb_t* warmup = esp_camera_fb_get();
  if (warmup) {
    Serial.printf("[camera] warm-up frame: %u bytes\n", (unsigned)warmup->len);
    esp_camera_fb_return(warmup);
  } else {
    Serial.println("[camera] warm-up frame: NULL");
  }
  return true;
}

static esp_err_t stream_handler(httpd_req_t *req) {
  static const char* BOUNDARY = "\r\n--frame\r\n";
  static const char* CONTENT_TYPE = "multipart/x-mixed-replace;boundary=frame";
  static const char* PART_HEADER = "Content-Type: image/jpeg\r\nContent-Length: %u\r\n\r\n";

  Serial.println("[stream] client connected");
  esp_err_t res = httpd_resp_set_type(req, CONTENT_TYPE);
  if (res != ESP_OK) { Serial.printf("[stream] set_type failed: %d\n", res); return res; }

  char part_buf[64];
  int frame_count = 0;
  while (true) {
    uint32_t t0 = millis();
    camera_fb_t* fb = esp_camera_fb_get();
    uint32_t t1 = millis();
    if (!fb) { Serial.println("[stream] fb_get returned NULL"); res = ESP_FAIL; break; }
    Serial.printf("[stream] frame %d: %u bytes, fb_get took %u ms\n", frame_count++, (unsigned)fb->len, (unsigned)(t1 - t0));
    res = httpd_resp_send_chunk(req, BOUNDARY, strlen(BOUNDARY));
    if (res == ESP_OK) {
      size_t hlen = snprintf(part_buf, sizeof(part_buf), PART_HEADER, fb->len);
      res = httpd_resp_send_chunk(req, part_buf, hlen);
    }
    if (res == ESP_OK) {
      res = httpd_resp_send_chunk(req, (const char*)fb->buf, fb->len);
    }
    esp_camera_fb_return(fb);
    if (res != ESP_OK) { Serial.printf("[stream] send_chunk failed: %d (client likely disconnected)\n", res); break; }
  }
  Serial.println("[stream] handler exiting");
  return res;
}

void startCameraServer() {
  httpd_config_t config = HTTPD_DEFAULT_CONFIG();
  config.server_port = 80;
  httpd_uri_t stream_uri = { .uri = "/stream", .method = HTTP_GET, .handler = stream_handler, .user_ctx = NULL };
  if (httpd_start(&stream_httpd, &config) == ESP_OK) {
    httpd_register_uri_handler(stream_httpd, &stream_uri);
  }
}

void setup() {
  Serial.begin(115200);
  delay(1000);
  Serial.println("IceDrone camera Wi-Fi smoke test - diagnostic only, NOT flight firmware");

  Serial.printf("Camera: %s\n", cameraInit() ? "OK" : "FAILED");

  WiFi.mode(WIFI_STA);
  WiFi.begin(WIFI_SSID, WIFI_PASS);
  Serial.printf("Connecting to %s", WIFI_SSID);
  while (WiFi.status() != WL_CONNECTED) {
    delay(500);
    Serial.print(".");
  }
  Serial.println();
  Serial.printf("Connected. IP: %s\n", WiFi.localIP().toString().c_str());

  startCameraServer();
  Serial.printf("Stream ready: http://%s/stream\n", WiFi.localIP().toString().c_str());
}

void loop() {
  delay(1000);
}

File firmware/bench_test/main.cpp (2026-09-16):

/*
 * IceDrone V3.4 bench-test firmware
 * Purpose: verify IMU, four PWM motor outputs and XIAO Sense camera BEFORE installing props.
 * This is NOT flight-control firmware.
 */
#include <Arduino.h>
#include <Wire.h>
#include <Adafruit_MPU6050.h>
#include <Adafruit_Sensor.h>
#include "camera.h"

static const int PIN_SDA = 2;
static const int PIN_SCL = 43;

// V3.4 motor map:
// 0 rear-left   -> GPIO4  / D3
// 1 rear-right  -> GPIO44 / D7
// 2 front-right -> GPIO6  / D5
// 3 front-left  -> GPIO5  / D4
static const int MOTOR_PINS[4] = {4, 44, 6, 5};

static const int PWM_HZ = 10000;
static const int PWM_BITS = 10;
Adafruit_MPU6050 mpu;

// ESP32 Arduino core 3.x LEDC API is pin-based (ledcAttach/ledcWrite take the
// GPIO directly); there is no separate channel argument to manage anymore.
void motorsOff(){ for(int i=0;i<4;i++) ledcWrite(MOTOR_PINS[i],0); }

void pulseMotor(int idx){
  if(idx<0 || idx>3) return;
  Serial.printf("Pulsing motor %d (GPIO%d) for 250 ms at 12%%. REMOVE PROPS.\n",
                idx, MOTOR_PINS[idx]);
  ledcWrite(MOTOR_PINS[idx],123);
  delay(250);
  ledcWrite(MOTOR_PINS[idx],0);
}

void setup(){
  Serial.begin(115200);
  delay(1000);
  Serial.println("IceDrone V3.4 bench test - PROPS MUST BE REMOVED");
  Serial.println("Motor map: 0=GPIO4, 1=GPIO44, 2=GPIO6, 3=GPIO5");

  // V3.4 mandatory custom I2C pins.
  Wire.begin(PIN_SDA, PIN_SCL, 400000);

  if(!mpu.begin(0x68,&Wire))
    Serial.println("WARN: MPU6050 not found. If using MPU9250/GY-91, use upstream Open32Drone IMU backend.");
  else
    Serial.println("MPU6050 detected.");

  for(int i=0;i<4;i++){
    ledcAttach(MOTOR_PINS[i],PWM_HZ,PWM_BITS);
  }
  motorsOff();

  Serial.printf("Camera: %s\n",cameraInit()?"OK":"FAILED");
  Serial.println("Commands: 0/1/2/3 pulse a motor; i = print IMU; c = capture one JPEG length; x = motors off");
}

void loop(){
  if(Serial.available()){
    char ch=Serial.read();
    if(ch>='0'&&ch<='3') pulseMotor(ch-'0');
    else if(ch=='x') motorsOff();
    else if(ch=='i'){
      sensors_event_t a,g,t;
      mpu.getEvent(&a,&g,&t);
      Serial.printf("ACC %.3f %.3f %.3f | GYR %.3f %.3f %.3f\n",
                    a.acceleration.x,a.acceleration.y,a.acceleration.z,
                    g.gyro.x,g.gyro.y,g.gyro.z);
    } else if(ch=='c'){
      size_t len=0;
      if(cameraCaptureJpegLength(len))
        Serial.printf("JPEG frame: %u bytes\n",(unsigned)len);
      else
        Serial.println("capture failed");
    }
  }
  delay(5);
}

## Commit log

2026-09-02 Add ESP32CAM MicroDrone V1 documentation, BOM and bench-test firmware
    Initial structured docs (BOM, electrical, mechanical, firmware, build/test,
    first flight, safety/legal DE, troubleshooting, sources), hardware tables
    (pin map, motor stage netlist), wiring diagram and bench-test firmware for
    the XIAO ESP32-S3 Sense based Open32Drone-derived quadcopter.
    Claude-Session: https://claude.ai/code/session_01HKFtDVqo6x4GML64vJckYR
    [bom.csv, motor_stage_netlist.csv, pinmap.csv]
2026-09-02 Add parametric CAD, real renders, detailed build guide and docs website
    - New OpenSCAD models (frame, camera cradle, battery cradle, prop guard)
    built directly from the dimensions already documented in 03_MECHANICAL.md,
    with STL exports and real rendered PNG previews (OpenSCAD + Xvfb),
    replacing the earlier "not yet included" placeholders.
    - Embed the real wiring diagram and CAD renders as images; keep Mermaid
    only for genuine diagrams (motor channel, frame layout, firmware
    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
    [battery_cradle_650.scad, battery_cradle_650.stl, camera_cradle_15deg.scad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]
2026-09-02 Add Amazon.de convenience order list chapter
    Dated, disposable shopping-link chapter (09) covering most of the BOM,
    found via web search on 2026-09-02. Explicitly marked as unverified
    convenience links rather than pinned sources, consistent with the
    existing "no frozen marketplace ASINs" policy in 01_BOM.md/SOURCES.md.
    Wired into docs navigation (index, prev/next footers, mkdocs nav).
    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
2026-09-02 Reconcile docs with actual ordered parts (BT2.0 battery, OV2640 camera)
    The real order deviated from the suggested list: the 1S battery/charger
    pair uses a BT2.0 connector instead of PH2.0, and the XIAO ESP32-S3
    Sense's camera is confirmed OV2640 rather than OV3660. Flag both
    build-relevant deviations in 09_AMAZON_ORDER_LIST_DE.md, 01_BOM.md,
    02_ELECTRICAL.md and 05_BUILD_AND_TEST.md so the wiring/camera
    assumptions match what is actually arriving.
    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
2026-09-05 Add parametric Airframe V2 OpenSCAD library
    [icedrone_v2_lib.scad]
2026-09-05 Add Airframe V2 OpenSCAD wrappers and validation data
    [PARTS_MANIFEST.csv, STL_VALIDATION.csv, assembly_preview_v2.scad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]
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2026-09-05 Promote Airframe V2 and switch previews to generated PNGs
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2026-09-05 Update project notice for Airframe V2 and propeller research CAD
2026-09-05 Add standard 75 mm replacement propeller OpenSCAD
    [icedrone_prop_75mm_standard.scad]
2026-09-05 Add toroidal low-noise research propeller OpenSCAD
    [icedrone_prop_75mm_toroidal.scad]
2026-09-05 Add 1 mm shaft-fit calibration coupon
    [shaft_fit_coupon_1mm.scad]
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2026-09-05 Remove superseded V1 frame CAD
    [frame_v1.scad]
2026-09-05 Remove superseded V1 CAD, STL and preview assets
    [battery_cradle_650.scad, battery_cradle_650.stl, camera_cradle_15deg.scad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]
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2026-09-05 Regenerate CAD STL and preview assets [skip ci]
    [IceDrone_1mm_Shaft_Fit_Coupon.stl, IceDrone_75mm_Standard_CCW.stl, IceDrone_75mm_Standard_CW.stl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]
2026-09-05 Fix bench_test firmware for ESP32 Arduino core 3.x, add platformio.ini
    - Add missing platformio.ini targeting seeed_xiao_esp32s3 (board defaults
    already use qio flash + opi psram, matching docs/04_FIRMWARE.md).
    - Move camera init/capture into camera.cpp/camera.h: esp_camera.h's
    sensor.h and Adafruit_Sensor.h both declare an incompatible sensor_t
    typedef, so they can no longer share a translation unit.
    - Replace removed ledcSetup/ledcAttachPin channel-based LEDC calls with
    the pin-based ledcAttach/ledcWrite API from core 3.x.
    Verified: builds and flashes clean on a real XIAO ESP32-S3 Sense over
    USB; boot log shows Camera: OK and the expected "MPU6050 not found"
    warning (IMU not wired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
    [camera.cpp, main.cpp]
2026-09-05 Add Wi-Fi camera smoke-test firmware, fix XCLK for reliable frame capture
    - New firmware/camera_wifi_test/: standalone diagnostic tool (no motors/
    IMU/flight code) that joins an existing Wi-Fi network and serves the
    XIAO Sense camera as an MJPEG stream at /stream, for viewing the
    camera before Open32Drone integration. Credentials live in a local,
    gitignored secrets.h (see secrets.h.example).
    - Root cause found on real hardware: xclk_freq_hz=20000000 let SCCB/
    esp_camera_init() succeed, but esp_camera_fb_get() then reliably
    returned NULL (0 usable frames). Dropping to 10 MHz plus a discarded
    warm-up frame after init fixed it. Applied the same fix to
    firmware/bench_test/camera.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
    [camera.cpp, main.cpp]
2026-09-06 Update camera XCLK comment: root cause was faulty camera module, not fixed HW limit
    Verified after swapping the camera module: at 20 MHz the new module
    captures reliably (468/468 frames over 20s stream test, 0 fb_get NULL
    errors). Confirms the original NULL-return issue was a marginal FPC
    ribbon seat on the old module, not an inherent XCLK ceiling. Kept the
    10 MHz setting as timing margin against future connector wear.
    Claude-Session: https://claude.ai/code/session_019UBRiEQb3HGCSs9vtXzRDf
    [camera.cpp, main.cpp]
2026-09-06 Vendor Open32Drone as submodule, apply V1 config patch, verify USB smoke test
    Adds vendor/open32drone (pinned at a49c037a) plus a small patch
    (firmware/open32drone/v1.patch) applying the two V1 policy deltas from
    docs/04_FIRMWARE.md that differ from upstream defaults: MJPEG quality
    10->18 and optical flow disabled. Everything else in that policy list
    (MAVLink port 14550, QVGA, one viewer max, SBUS disabled, battery
    divider 2.0) already matches upstream.
    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
2026-09-06 Update docs site with real-hardware bring-up status
    Reflects the 2026-09-06 bring-up session: bench-test firmware and the
    camera_wifi_test diagnostic tool verified on physical hardware, and
    Open32Drone vendored/patched with a passing USB-only smoke test.
    Adds a troubleshooting entry for the esp_camera_fb_get() NULL issue
    (XCLK frequency + a possible marginal FPC ribbon seat) so future
    bring-up sessions don't have to rediscover it. No credentials, SSIDs
    or private IPs added.
    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
2026-09-16 hardware: add authoritative V3.4 perfboard netlist
    [perfboard_v34_netlist.csv]
2026-09-16 hardware: add V3.4 perfboard pin matrix
    [perfboard_v34_pin_matrix.csv]
2026-09-16 hardware: update pin map to V3.4
    [pinmap.csv]
2026-09-16 hardware: update motor stage to V3.4 components
    [motor_stage_netlist.csv]
2026-09-16 firmware: switch bench test to V3.4 motor map
2026-09-16 bom: update parts for V3.4 hardware
    [bom.csv]
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2026-09-16 docs: update build and test flow for V3.4
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2026-09-18 bom: add Sn42Bi58 reflow tooling BOM
    [reflow_bom.csv]
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2026-09-19 bom: mark received Sn42Bi58 paste and label particle size
    [reflow_bom.csv]
2026-09-19 bom: record received Amazon A09T AO3400A MOSFETs
    [bom.csv]
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2026-09-19 bom: clarify SS14 only for D5; require 3A SS34-class motor diodes
    [bom.csv]
2026-09-19 docs: document unavailable SS14 listing and V3.4 diode requirement
2026-09-19 bom: record BEEYUIHF capacitor kit and distinguish ceramic capacitors
    [bom.csv]
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2026-09-19 bom: document available workshop electrolytic kit vs V3.4 C1/C2
2026-09-19 bom: add workshop capacitor inventory
    [workshop_capacitor_inventory_v34.csv]
2026-09-19 bom: mark SS34 diodes received and correct capacitor-kit assumptions
    [bom.csv]
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2026-09-19 bom: add V3.4 PCB SMD bench inventory
    [pcb_smd_inventory_v34.csv]
2026-09-19 docs: link V3.4 PCB SMD inventory and missing-parts list
2026-09-19 docs: clarify confirmed SS14 strips and PCB footprint limits
2026-09-19 bom: add 16V SMD C2 candidate for V3.4 first article
    [pcb_smd_inventory_v34.csv]
2026-09-19 bom: add Amazon JTAREA 0603 assortment option
    [pcb_smd_inventory_v34.csv]
2026-09-19 docs: add Amazon 0603 assortment recommendation for PCB reflow
2026-09-19 bom: confirm D5 and bulk-cap SMD footprints from Eurocircuits production preview
    [pcb_smd_inventory_v34.csv]
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2026-09-19 bom: add Amazon set options for D5 and C1/C2
    [pcb_smd_inventory_v34.csv]
